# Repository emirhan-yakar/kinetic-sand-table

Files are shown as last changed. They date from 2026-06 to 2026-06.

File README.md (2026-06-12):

<div align="center">

DEVRAN

### Kinetik Kum Sanatı Masası · Polar (θ-ρ) · Ø60 cm

Çelik bir bilyeyi kumun altından mıknatısla sürükleyerek sonsuz desen çizen,
**Türkiye'de üretilebilir**, açık tasarımlı premium kinetik sanat masası.






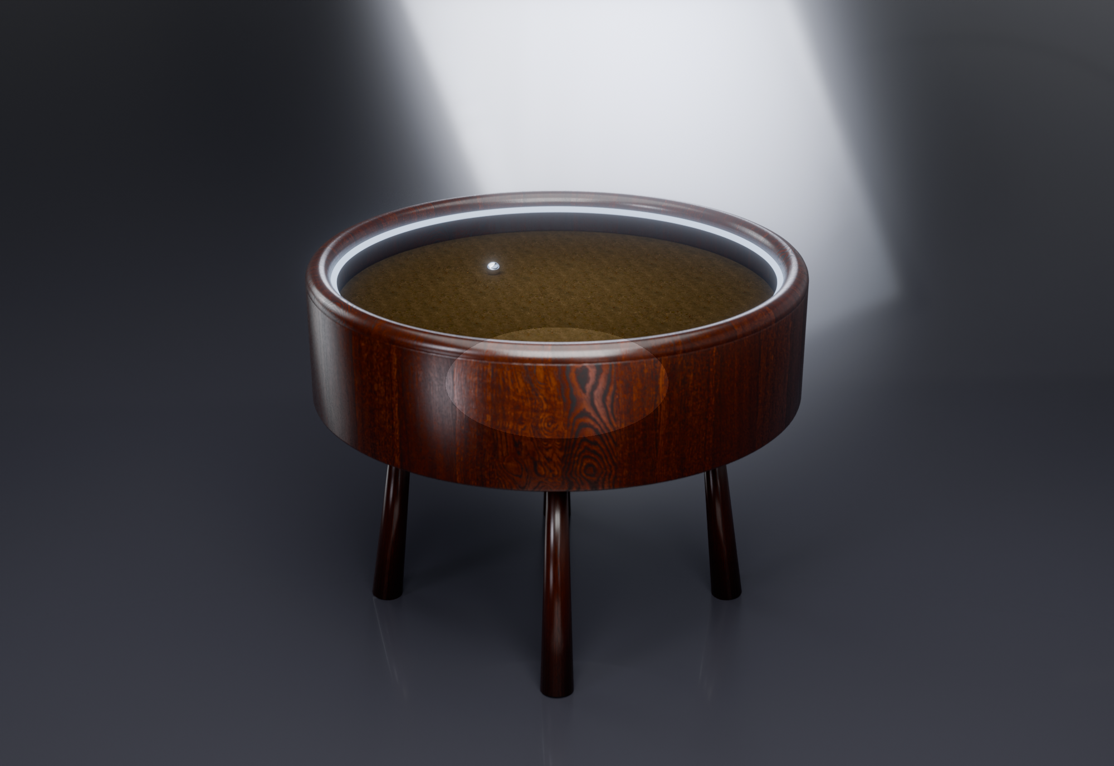
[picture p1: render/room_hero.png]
DEVRAN render


</div>

---

## Bu nedir?

DEVRAN, cam yüzeyin altında dönen bir kol (**θ** ekseni) ve kol üzerinde kayan bir taşıyıcının
(**ρ** ekseni) bir **N52 mıknatısı** taşıdığı, bu mıknatısın üstteki kumda bir **çelik bilyeyi**
sürükleyerek desen kazıdığı bir Sisyphus tipi kinetik masadır. Kenardaki **WS2812B LED halka**
ambiyans ışığı verir. Beyin bir **ESP32 + FluidNC**'dir; `.thr` (theta-rho) desenlerini oynatır.

Bu repo **fikirden satılabilir ürüne** giden tüm mühendislik + üretim dosyalarını içerir.

## Öne çıkanlar

- 🌀 Sonsuz, tekrarsız kinetik kum deseni (Atatürk imzası, spiral, özel)
- 🔇 Sessiz çalışma (TMC2209) · 💡 adreslenebilir LED ambiyans
- 📶 Wi-Fi / WebUI kontrol · SD desen kütüphanesi
- 🪵 Premium ceviz gövde + temperli cam · 🇹🇷 yerli üretilebilir
- 🔓 Açık kaynak yazılım (FluidNC + Dune Weaver)

## Üretim paketi

| Alan | Dosyalar |
|---|---|
| **Kontrol kartı** | KiCad Rev-B · Gerber · STEP · [JLCPCB paketi](hardware/pcb/jlcpcb/) (BOM+CPL) · [inceleme](docs/uretim/PCB_inceleme.md) |
| **Mekanizma** | [θ/ρ kinematik + kesit + hesap](docs/uretim/mekanizma_tasarim.md) |
| **Mekanik üretim** | [DXF + STEP](docs/uretim/dxf/) (şasi/ayak/kol) · [teknik çizim](docs/uretim/MONTAJ_CIZIM.pdf) · [montaj](docs/uretim/montaj.md) |
| **Elektrik** | [harness + pinout](docs/uretim/elektrik_montaj.md) · [talimat PDF](docs/uretim/ELEKTRIK_TALIMATI.pdf) · [QA/FCT](docs/uretim/QA_kontrol_listesi.md) |
| **Firmware** | [FluidNC config](firmware/fluidnc_config.yaml) · [mimari](firmware/README.md) |
| **İş** | [üretim dosyası (NPI)](docs/uretim/URETIM_DOSYASI.md) · [datasheet](docs/DEVRAN_datasheet.pdf) · [pitch](docs/DEVRAN_pitch.pdf) · [BOM/maliyet](docs/uretim/BOM_uretim.md) |
| **Görsel** | render + reklam videosu (`render/`) · interaktif 3D sim (`render/viewer.html`) |

> 🌐 **Web sitesi:** kök `index.html` (yerel: `python3 -m http.server`) — GitHub Pages açılırsa canlı.

## Durum (dürüst)

| Alt sistem | Durum |
|---|---|
| Mekanik tasarım | 🟡 Tasarlandı (kinematik + çizim + DXF/STEP) — fiziksel prototip yok |
| Kontrol kartı (PCB) | 🟠 Rev-B, DRC temiz — **fiziksel üretilmedi/test edilmedi** |
| Firmware | 🟠 Mimari + config hazır — cihazda doğrulanmadı |
| BOM / maliyet / görsel | 🟢 Hazır |

**Sıradaki:** Fusion'da COTS fit doğrulama → PCB sipariş → bring-up → kalibrasyon → EVT/DVT.

## Maliyet & fiyat

Seri COGS ≈ **7.800 TL** (~$230) → hedef **MSRP ≈ 21.900 TL** (~$650, ~%64 brüt marj).
Benzer ürün $699. Yazılım açık kaynak (0 TL). Detay: [BOM/maliyet](docs/uretim/BOM_uretim.md).

## Repo yapısı

```
hardware/pcb/   KiCad tasarım, Gerber, STEP, JLCPCB paketi (üretim scriptleri)
firmware/       FluidNC config + desen üreteçleri (.thr)
render/         Blender sahne (scene.py), render'lar, reklam videosu, 3D sim (viewer.html)
docs/uretim/    mekanizma, montaj, elektrik, QA, BOM, DXF+STEP, teknik çizim/PDF'ler
docs/           datasheet, pitch, gerçeklik yol haritası
*.html          web sitesi (build_site.py ile MD'den üretilen sayfalar dahil)
```

## Yeniden üretmek

```bash
# Site (MD -> HTML sayfalar)        : python3 build_site.py
# Render/video (Blender 4.5)        : Blender --background --python render/scene.py -- hero|video
# PCB (KiCad 9 + Freerouting)       : hardware/pcb/freeroute.sh
# DXF/STEP                          : python3 docs/uretim/dxf/make_dxf.py && make_step.py
# Datasheet/pitch                   : python3 docs/marka_pdf.py
```

## Lisans & katkı

Açık kaynak tasarım. Ticari üretim için: PCB **fiziksel doğrulama** + **CE/elektrik güvenlik**
belgesi gereklidir. Katkı/issue/PR memnuniyetle. Tüm değişiklikler: [CHANGELOG.md](CHANGELOG.md).

<div align="center"><sub>DEVRAN · kinetik kum sanatı masası · github.com/emirhan-yakar/kinetic-sand-table</sub></div>

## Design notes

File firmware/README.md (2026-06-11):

# Firmware & Yazılım — gerçek mimari

> **Durum:** Mimari + config **hazır**; cihaza yüklenip **doğrulanmadı** (PCB henüz üretilmedi).
> Hazır açık kaynak yazılım kullanılır — sıfırdan firmware yazmaya gerek yok.

## Mimari
Kinetik kum masaları iki katmanlı çalışır:

1. **Hareket: ESP32 + FluidNC** — G-code yorumlar, TMC2209 sürücülerle θ/ρ motorlarını sürer.
   - Pinler kontrol kartıyla eşleşir: **`fluidnc_config.yaml`** (bu klasörde).
   - FluidNC'nin kendi **WebUI**'si var; SD karttan G-code oynatabilir.
2. **Desen/UX: Dune Weaver (opsiyonel, Raspberry Pi)** — `.thr` desen kütüphanesi, canlı
   önizleme, **LED senkron (WLED)**, zamanlama. `.thr`'yi G-code'a çevirip FluidNC'ye gönderir.

```
.thr (Sandify/Dune Weaver) --(theta-rho -> G-code)--> FluidNC (ESP32) --> TMC2209 --> motorlar
                                                          └ WebUI / SD
LED: WS2812B  <-- WLED veya Dune Weaver LED modulu (idle/playing/scheduled)
```

**İki seçenek:**
- **A (sade, EVT):** Sadece FluidNC. Desenler offline `.thr→G-code` çevrilip SD'ye/WebUI'a.
- **B (tam UX, ürün):** A + Raspberry Pi Zero 2 W'de Dune Weaver app (+~500 ₺).

## Kurulum
1. **FluidNC yükle** (ESP32): https://github.com/bdring/FluidNC — web installer (`http://install.fluidnc.com`) veya esptool.
2. `fluidnc_config.yaml`'i karta yükle (FluidNC WebUI → Files veya SD). Pinler PCB ile eşleşir.
3. **Kalibrasyon (donanımda, ZORUNLU):**
   - `steps_per_mm` (X=ρ ve A=θ) gerçek dişli/mikroadıma göre ayarla (config'deki değerler tahmini).
   - ρ home (endstop) yönü/menzili; θ tam tur = doğru derece.
   - TMC2209 akımı ~0.6–0.9A (standalone'da pot/UART'da config).
4. **Desen akışı:** `firmware/patterns/*.thr` (Atatürk imza, spiral, klasik) → Sandify/Dune Weaver
   ile G-code'a çevir → oynat. (Üretici: `firmware/patterns/*.py`.)
5. **Dune Weaver (opsiyonel):** Raspberry Pi'ye kur (https://github.com/tuanchris/dune-weaver),
   FluidNC'yi seri/USB ile bağla, `.thr` kütüphanesi + LED + zamanlama.

## LED (WS2812B)
- **WLED** (ESP ayrı veya aynı) ya da Dune Weaver LED modülü ile sürülür — idle/playing/scheduled modları.
- Donanım notu: 3.3V→5V **level shifter** gerekir (bkz. `docs/uretim/PCB_inceleme.md` #2).

## Önemli — dürüst notlar
- Bu config **donanımda doğrulanmadı**; ilk bring-up'ta pin/yön/akım testleri gerekir
  (`docs/uretim/URETIM_DOSYASI.md` §5).
- İlk prototipte **standalone TMC** (UART yok) önerilir — daha az risk; UART'ı DVT'de ekle.
- Polar kinematik: θ = sürekli dönme (A ekseni), ρ = lineer (X ekseni). `.thr` (theta rad, rho 0..1)
  → G-code (A derece, X = rho×max_yarıçap). Çevrim Sandify/Dune Weaver tarafında.

## Dosyalar
- `fluidnc_config.yaml` — FluidNC pin/eksen config (PCB ile eşleşir)
- `patterns/` — `.thr` desenleri + üreteçler (imza izi, spiral, görüntü→theta-rho)

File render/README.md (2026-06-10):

# Blender Fotogerçekçi Render

Kinetik kum sanatı masasının (Ø60cm) prosedürel Blender sahnesi ve Cycles render'ı.
Geometri `hardware/sand_table.scad` ölçüleriyle kod içinde kurulur — harici STL/model gerekmez.

## Çalıştırma
```
BL=~/Applications/Blender.app/Contents/MacOS/Blender
"$BL" --background --python render_table.py -- hero    # aydınlık ürün çekimi
"$BL" --background --python render_table.py -- dark    # koyu LED parıltılı çekim
```
Çıktı: `table_hero.png`, `table_dark.png` (1600×1200, Cycles, Metal GPU + OpenImageDenoise).

## Çıktılar
| Dosya | Açıklama |
|---|---|
| `table_hero.png` | Aydınlık stüdyo: mat ceviz gövde + taranmış konsantrik kum deseni + çelik bilye + LED halka |
| `table_dark.png` | Koyu stüdyo: cam görünür, mavi LED halka kumu/camı aydınlatır (ambiyans) |

## Sahne özeti (`render_table.py`)
- **Geometri:** ahşap gövde (üst kısma boolean ile kum havuzu oyulur), kum diski,
  cam üst (hero'da kameradan gizli → desen net), çelik bilye, LED torus halka, ahşap çerçeve.
- **Malzemeler (Principled BSDF):** ceviz (prosedürel Wave damar, mat), cam (transmission 1,
  roughness 0.02, IOR 1.5), kum (Wave RINGS `Z` → konsantrik oluk bump + ince gren noise),
  çelik (metallic), LED (Emission).
- **Işık:** 4 area light (key/fill/rim/top) düşük `specular_factor` (cam/bilye ışık aynalamasın),
  yumuşak stüdyo dünyası. Dark modda key+rim azaltılıp LED gücü artırılır.
- **Kamera:** 50mm, 3/4 yüksek açı, DOF f/5.6.
- **Ton eşleme:** Filmic Medium Contrast.

## Ayar ipuçları
- Kum deseni belirginliği: `wring` Scale/Distortion + `bumpS` Strength.
- Pozlama: area light `energy` ve world `Strength`; oluk gölgesi için Top ışığı kıs, Key (yan) koru.
- Kalite: `scene.cycles.samples` (220 → 300+).
- Ayrıntılı malzeme/ışık reçetesi: `../docs/render-recipe.md`.

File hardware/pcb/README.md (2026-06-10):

# Kontrol Kartı / PCB Spesifikasyonu

## Strateji
- **Prototip (1–10 adet):** Özel PCB tasarlama. Hazır **MKS DLC32** veya
  **BTT** ESP32 tabanlı kontrol kartı kullan — TMC2209 sürücü yuvaları,
  endstop ve LED çıkışı hazır. Riski sıfırlar, hızlı doğrulama sağlar.
- **Seri (50+ adet):** Maliyet ve montaj için aşağıdaki tek kartı KiCad'de
  tasarla, **JLCPCB / PCBWay** (Çin, ucuz, SMT montaj dahil) veya yurt içi PCB
  firmasında bastır.

## Özel PCB — blok şema
```
            +12V DC giriş (fiş + ters polarite koruma D1)
               │
        ┌──────┴───────┐
   12V →│ Buck 12V→5V   │→ +5V (ESP32, LED, lojik)
        └──────────────┘
               │5V                          │12V
        ┌──────┴───────┐            ┌────────┴─────────┐
        │   ESP32-WROOM │            │ TMC2209 #1 (θ)   │→ NEMA17 θ
        │   -32         │── UART ───▶│ TMC2209 #2 (ρ)   │→ slip ring → NEMA17 ρ
        │               │   STEP/DIR └──────────────────┘
        │   GPIO ───────┼─[330Ω]─▶ DIN  WS2812B LED halka
        │   3v3 lojik   │          (5V güç + 1000µF kondansatör)
        │   GPIO ◀──────┼── endstop (θ home opto/mikro switch)
        └───────────────┘
```

## Pin haritası (Dune Weaver firmware ile uyumlu — `firmware/` bkz.)
| İşlev | ESP32 GPIO | Not |
|---|---|---|
| θ STEP / DIR | 19 / 18 | TMC2209 #1 |
| ρ STEP / DIR | 21 / 5 | TMC2209 #2 (sinyaller slip ring'den) |
| TMC UART (her ikisi) | 17 (TX)/16 (RX) | tek hat, adresli |
| EN (ortak) | 25 | sürücü enable |
| θ endstop / home | 22 | opto veya mikro switch |
| WS2812B DIN | 4 | seri direnç 330Ω |
| Buck enable / fan | 23 | opsiyonel |

## KiCad bileşen listesi (özel PCB)
- ESP32-WROOM-32E modülü (veya ESP32-DevKit header)
- 2× TMC2209 step sürücü (modül soketi veya SMD)
- MP1584 / LM2596 buck (12V→5V, ≥3A) — LED akımı için 5V hattını boyutlandır
- Giriş: DC jack/klemens, P-MOSFET ters polarite koruma, TVS diyot
- WS2812 hattı: 330Ω seri direnç + 1000µF/16V elektrolitik kondansatör
- Endstop konnektörü, motor için 4'lü JST/klemens (×2), slip ring klemensi
- Decoupling: 100nF × bolca, ESP32 EN/BOOT için RC + butonlar (programlama)

## Slip ring notu (KRİTİK — yuvarlak masaya özel)
Kol sürekli döndüğü için **ρ motorunun 4 bobin kablosu** dönen koldan sabit
karta **slip ring** üzerinden gelir. En az **6 kanallı** kapsül slip ring seç
(4 motor + 2 yedek/LED). Sinyal yerine motor bobinlerini geçirmek en basitidir
(ρ sürücüsü sabit kartta kalır). Slip ring kontak direnci düşük olmalı; ρ
akımını TMC2209'da makul (~0.6–0.9A) tut.

---

# ÜRETİLEN DOSYALAR

Kart, KiCad olmadan saf Python (`gerbonara`) ile **kod olarak** tasarlandı.
Yeniden üretmek için:
```
pip install --user gerbonara
python3 pcb_gen.py
```

## Dosya manifestosu
| Yol | İçerik |
|---|---|
| `pcb_gen.py` | Kartı üreten script (yerleşim + yönlendirme + GND plane + render) |
| `board3d.scad` | Kartın **3D dizgi modeli** (OpenSCAD → STL) |
| `controller.net` | KiCad'e aktarılabilir **netlist** (26 net) |
| `gerbers/*.gtl .gbl .gts .gbs .gto .gbo .gko` | Gerber katmanları (RS-274X) |
| `gerbers/controller-PTH.drl` / `-NPTH.drl` | Excellon delik dosyaları |
| `plots/*.svg` (+ `.png`) | Her katmanın çizimi + üst/alt kompozit + **assembly drawing** |

## Katman dizilimi (stackup) — 2 katman, 1.6mm FR4
| Gerber | KiCad adı | İçerik |
|---|---|---|
| `.gtl` | F.Cu | üst bakır: sinyal + güç izleri, padler |
| `.gbl` | B.Cu | **GND ground plane** (clearance'lı dolgu) |
| `.gts`/`.gbs` | F/B.Mask | lehim maskesi açıklıkları |
| `.gto`/`.gbo` | F/B.Silkscreen | bileşen konturları, pin-1, ratsnest kılavuzu |
| `.gko` | Edge.Cuts | kart sınırı 100×75mm + 4× Ø3.2 montaj deliği |

## Katman çizimleri (plots/)
- `composite-top.svg` / `composite-bottom.svg` — üst/alt birleşik görünüm
- `top_cu.svg`, `bot_cu.svg` (GND plane), `*_mask`, `*_silk`, `edge`
- `assembly.svg` — etiketli yerleşim/dizgi çizimi (montaj için)

## Yönlendirme durumu
- GND tamamen **alt katman ground plane** ile çözüldü (router'a girmez).
- Sinyal + güç: **26/32 segment** otomatik yönlendirildi (çakışma kontrollü).
- Kalan **6 segment** üst silk'te **kesik çizgi (ratsnest)** olarak işaretli —
  yoğun ESP32 çevresi sinyalleri. Bunlar KiCad'de elle/autorouter ile tamamlanır.

## ⚠️ Üretim öncesi (ZORUNLU)
Bu Gerber'lar geometrik olarak geçerlidir ve fabrikaya yüklenebilir, ancak
**seri üretimden önce KiCad'de DRC** (tasarım kuralı kontrolü) çalıştırılmalı:
1. KiCad → yeni PCB → `controller.net` ile **"Update PCB from netlist"**.
2. `gerbers/` Gerber'larını referans alarak yerleşimi içe aktar veya yeniden yerleştir.
3. 6 ratsnest segmentini tamamla, **DRC** çalıştır (clearance, annular ring).
4. `kicad-cli pcb export gerbers` ile doğrulanmış final Gerber + `step` 3D üret.

## Fabrikaya gönderim (JLCPCB / PCBWay)
- `gerbers/` klasörünü zip'le → yükle. 2 katman, 1.6mm, HASL, 5/5 mil rahat.
- Delikler: PTH (`-PTH.drl`) + NPTH (`-NPTH.drl`, montaj delikleri).
- Adetli dizgi (SMT) istiyorsan: özel PCB'yi SMD bileşenlerle tasarlayıp
  BOM + CPL ekle. Prototipte modüller (ESP32/TMC/buck) header'a takılır → elde lehim.

## Kart üzeri bileşenler (BOM özeti)
| Ref | Bileşen | Not |
|---|---|---|
| U1 | ESP32-DevKitC (2×15) | beyin |
| A1/A2 | TMC2209 StepStick | θ / ρ sürücü |
| BK1 | MP1584 buck | 12V→5V |
| J1 | 2p klemens | 12V giriş |
| J2/J3 | 4p klemens | θ / ρ motor (J3 slip ring'e) |
| J4 | 3p klemens | WS2812B LED (5V/DIN/GND) |
| J5 | 3p klemens | endstop (3V3/SIG/GND) |
| R1 | 330Ω 0805 | LED DIN seri direnç |
| C1 | 1000µF | 5V tampon |
| C2/C3 | 100nF 0805 | sürücü decoupling |

---

# KİCAD İLE FİNAL ÇIKTI (Gerber + STEP 3D)

Kart artık gerçek bir **KiCad 9 projesi** olarak da üretiliyor — gerçek footprint'ler,
net'ler, GND ground plane ve KiCad'in kendi motoruyla export edilmiş Gerber + STEP.

## Araç zinciri
```
python build_kicad.py   # pcbnew API ile controller.kicad_pcb uretir
bash   kicad_export.sh   # kicad-cli ile final/ -> Gerber + STEP + PDF + DRC
```
> KiCad ~/Applications/KiCad.app altında (9.0.9). `build_kicad.py` KiCad'in
> kendi python'u ile çalışır (bkz. script başı / kicad_export.sh içindeki yol tespiti).

## Üretilen dosyalar
| Yol | İçerik |
|---|---|
| `controller.kicad_pcb` | KiCad PCB (GUI'de açılır) — yerleşim + 25 net + GND zone |
| `build_kicad.py` | pcbnew ile kartı kuran script (footprint + net + iz + zone) |
| `kicad_export.sh` | kicad-cli export (Gerber/Drill/STEP/PDF/DRC) |
| `final/gerbers/*.gbr` + `controller.drl` | **KiCad'in ürettiği final Gerber + Excellon** |
| `final/controller.step` | **STEP 3D model** (2.1 MB, ISO-10303, e-CAD/mekanik için) |
| `final/top.pdf` / `bottom.pdf` | katman PDF çıktıları |
| `final/drc.json` + `DRC_SUMMARY.txt` | DRC raporu |
| `final/plots/final-B_Cu-groundplane.png` | alt katman GND plane render'ı |

## Durum — Freerouting ile TAM ROUTING ✅
- ✅ **Tüm sinyaller routlu** — DRC **ratsnest = 0** (Freerouting 23 sinyal netini
  tamamladı: 139 iz segmenti + 3 via).
- ✅ **Bakır kısa devre yok** (DRC `shorting_items = 0`).
- ✅ **Bakır clearance ihlali yok** (zone clearance kuralı self-fill geometrisine
  göre ayarlandı).
- ✅ **GND ground plane** alt katmanda dolu (clearance'lı), Gerber'da mevcut.
- ✅ **STEP 3D** geçerli (jenerik MaiXu klemens STEP modeli kütüphanede yok, atlandı).
- ⚠️ Kalan **148 DRC ihlali kozmetik**: 129'u `silk_*` (KiCad kütüphane
  footprint'lerinin kendi silkscreen'i pad/birbirine biniyor — fabrikalar kabul eder),
  geri kalan ~12'si self-fill plane artefaktı (`isolated_copper`, `starved_thermal`).
  **KiCad GUI'de `B` (Fill All Zones)** ile yeniden doldurunca bunlar da temizlenir.

## Freerouting akışı (otomatik routing)
`pcbnew` DSN export'u headless'ta çalışmadığı için DSN'i geometriden ürettik,
SES'i kendimiz ayrıştırdık. Java 25 + Freerouting 2.2.4 gerekir.
```
JAVA=~/jdk25/.../java FREEROUTING_JAR=/path/freerouting.jar bash freeroute.sh
```
| Script | İş |
|---|---|
| `make_dsn.py` | `controller.kicad_pcb` → Specctra **`controller.dsn`** (GND = B.Cu plane) |
| (Freerouting) | `controller.dsn` → **`controller.ses`** (headless autoroute) |
| `build_kicad.py` (`SES_FILE=...`) | SES route'larını fresh board'a uygula + GND plane yeniden doldur |
| `freeroute.sh` | yukarıdakileri zincirler + `kicad_export.sh` |

## Üretim öncesi son adım (KiCad GUI'de)
1. `controller.kicad_pcb`'yi aç → **`B`** ile zone'ları yeniden doldur (kozmetik DRC temizliği).
2. İstersen silkscreen referans metinlerini görünür yap / yeniden konumla.
3. **DRC** → `kicad_export.sh` ile final Gerber/STEP'i tazele.

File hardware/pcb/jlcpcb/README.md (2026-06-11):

# JLCPCB Üretim Paketi — Rev-B

Kontrol kartını **JLCPCB**'de (veya PCBWay) üretip dizdirmek için hazır dosyalar.

> ⚠️ **Bu Rev-B tasarımıdır — fiziksel olarak henüz test EDİLMEDİ.** Üretim öncesi
> bir donanımcının son incelemesi önerilir (`../../../docs/uretim/PCB_inceleme.md`).
> İlk siparişte **5 adet** (yedekli) öneririz.

## Dosyalar
| Dosya | Ne |
|---|---|
| `gerbers_revB.zip` | Fab dosyaları (Gerber + Excellon) — JLCPCB "Add gerber file" |
| `BOM_jlcpcb.csv` | SMD dizgi malzeme listesi (Comment, Designator, Footprint, LCSC) |
| `CPL_jlcpcb.csv` | Pick & place konumları (Designator, Mid X/Y, Layer, Rotation) |
| `pos_raw.csv` | KiCad ham pozisyon (ara dosya) |

## JLCPCB akışı
1. **PCB:** gerbers_revB.zip yükle → 2 katman, 1.6mm, HASL (veya ENIG). Önizlemede kontrol et.
2. **Assembly (SMT):** "PCB Assembly" aç → **BOM_jlcpcb.csv** + **CPL_jlcpcb.csv** yükle.
3. **Parça eşleştir:** her satır LCSC ile eşleşmeli. `DOGRULA` yazan 3 parça (aşağıda) JLCPCB
   kütüphanesinden seçilmeli. Diğerleri (R/C/Q1) yaygın Basic parçalar.
4. **Rotation/önizleme:** JLCPCB dizgi önizlemesinde **her parçanın dönüşünü kontrol et**
   (KiCad↔JLCPCB rotasyon farkı olabilir — özellikle SOT-23/SOT-23-5 ve polariteli D1).
5. Sipariş → ~$30–60 (5 adet, ekonomik SMT).

## ⚠️ LCSC doğrulanacak (3 parça)
| Ref | Parça | Not |
|---|---|---|
| **U2** | 74AHCT1G125 (SOT-23-5) | 3.3→5V level shifter. JLCPCB'de yoksa eşdeğer (74LVC1G125 + dikkat) veya Extended. |
| **D1** | 10V zener (SOD-323) | BZT52C10 / MMSZ5240 — polariteyi önizlemede doğrula. |
| **F1** | PTC sigorta 1206 | Akıma göre seç (~3A hold). |

> Tüm LCSC kodları sipariş anında **stok/geçerlilik** açısından doğrulanmalı (kodlar değişir).

## Elle lehimlenecek (JLCPCB SMT'ye DAHİL DEĞİL)
Bunlar modül/soket/klemens — kart geldikten sonra elle takılır/lehimlenir:
- **U1L/U1R** — ESP32-DevKitC için 1×15 soketler (modül takılır)
- **A1/A2** — TMC2209 modülleri için 2×08 soketler
- **BK1** — buck modülü için 1×04 soket
- **J1–J5** — vidalı klemensler (12V, θ/ρ motor, LED, endstop)
- **C1 (1000µF), C6 (100µF)** — elektrolitik kondansatörler (THT)

## Üretim sonrası
Kart geldiğinde **bring-up testi** yap: `../../../docs/uretim/URETIM_DOSYASI.md` §5.1
(motor bağlamadan güç → 5V ölç → FluidNC flash → UART adres oku → LED test).

## Yeniden üretmek
```
kicad-cli pcb export pos --format csv --units mm --side both --use-drill-file-origin -o jlcpcb/pos_raw.csv controller.kicad_pcb
python3 make_jlcpcb.py
```

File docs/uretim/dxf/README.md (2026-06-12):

# CNC / Lazer Kesim DXF Dosyaları

Alüminyum şasi, ayak plakası ve dönen kol için 2D kesim dosyaları (mm, DXF R2010).
Lazer / CNC router / su jeti atölyesine doğrudan gönderilebilir.

| Dosya | Parça | Malzeme / kalınlık | Adet |
|---|---|---|---|
| `sasi.dxf` | Mekanizma şasi diski Ø520 | Alüminyum **6082 / 5754, 4 mm** | 1 |
| `ayak_plakasi.dxf` | Ayak bağlantı plakası 60×60 | Alüminyum 4 mm veya çelik 3 mm | **4** |
| `kol.dxf` | Dönen kol (θ) 320×40 | Alüminyum 5 mm | 1 |

Her `.dxf` yanında `*_preview.png` (görsel kontrol).

## 3D STEP (mekanik CAD doğrulama)
Aynı parçalar **3D katı** olarak da var (`*.step`) — Fusion 360 / FreeCAD / SolidWorks'te
açıp montaj/fitment doğrulamasına başlamak için (`make_step.py`, cadquery ile üretildi):
`sasi.step` (Ø520×4, 820 cm³) · `ayak_plakasi.step` (60×60×4) · `kol.step` (320×40×5).
> Bunlar **kesim parçalarının** katılarıdır; tam fitment için satın alınan COTS parçaları
> (MGN12 ray, lazy-susan, slip ring, NEMA17) CAD'e ekleyip doğrula.

## Delik şeması (özet)
- **Şasi:** dış Ø520 · drum bağlantı 4× M4 @ Ø500 PCD · merkez Ø90 (slip ring + kayış boşluğu) ·
  turntable 4× M4 @ Ø120 · θ motor NEMA17 (Ø22 + 4× M3 @ 31×31, offset) · PCB 4× M3 (92×67) · kablo yuvası.
- **Ayak plakası:** 60×60 · 4× M5 @ 36×36 · merkez Ø20 (ayak tenon). **8° splay açısı plakada değil,
  eğimli ayak/braket veya ara takozda** verilir (DXF düz kesimdir).
- **Kol:** pivot ucu 4× M3 @ Ø30 + merkez Ø8 · MGN12 ray M3 @ 20 mm · ρ motor NEMA17 ucu.

## ⚠️ Üretim öncesi doğrulama (ZORUNLU)
Delik konumları **temsilidir** — atölyeye göndermeden önce **gerçek parçalarla** doğrula:
- **MGN12 ray** delik pitch'i (20 vs 25 mm) → satın alınan raya göre.
- **Lazy-susan / turntable** civata dairesi → satın alınan rulmana göre.
- **Slip ring** gövde/bore çapı → seçilen modele göre (merkez Ø90 boşluk).
- **NEMA17** = standart (31×31 M3, Ø22 pilot) ✓.
- Toleranslar: gecme delikler (M3=3.2, M4=4.5, M5=5.5); sıkı geçme gerekiyorsa düşür.

> Bunlar 2D **kesim** dosyalarıdır; 3D montaj/açı için `montaj.md`, `montaj_sheet.svg`,
> `montaj_patlatma.png`. Nihai mekanik CAD (Fusion 360 / SolidWorks) ile son kontrol önerilir.

## Yeniden üretmek
```
python3 make_dxf.py    # ezdxf gerekir:  pip install ezdxf
```
Ölçüler `make_dxf.py` başındaki sabitlerden (montaj_hesap.py ile tutarlı) gelir.

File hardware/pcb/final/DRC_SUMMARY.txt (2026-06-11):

KiCad 9.0.9 DRC -- Rev-B (Freerouting tam routing)
ratsnest: 0 | bakir short: 0 | bakir clearance: 1
toplam ihlal: 171 (cogu kozmetik silk + plane artefakti; GUI 'B' refill ile temizlenir)
    73 silk_over_copper
    73 silk_overlap
    10 isolated_copper
     6 starved_thermal
     3 courtyards_overlap
     2 solder_mask_bridge
     2 silk_edge_clearance
     1 clearance
     1 hole_clearance

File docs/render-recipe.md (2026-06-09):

# Fotogerçekçi Render Reçetesi (Blender Cycles / KeyShot)

`hardware/sand_table.scad` modelinden STL al → Blender'a import et (veya Fusion
360'ta yeniden modelleyip KeyShot'a gönder). Aşağıdaki reçete tanıtım/ürün
görseli kalitesinde sonuç verir.

## 1) Model hazırlığı
- OpenSCAD'de `EXPLODE=0`, `SHOW_GLASS=true`, `SHOW_SAND=true` → Export STL.
- Blender: Import STL → ölçek mm→m (0.001) kontrol et → `Shade Smooth` gövde.
- Kum yüzeyine **gerçek desen** için: Sandify'dan bir `.thr`/SVG yörüngesini
  curve olarak import et, ince oluk (displacement) olarak kuma uygula.

## 2) Malzemeler (Principled BSDF)
| Parça | Ayar |
|---|---|
| Ahşap gövde | Base color koyu ceviz doku (Roughness 0.4, hafif clearcoat) |
| Cam üst | Transmission 1.0, Roughness 0.02, IOR 1.5, ince kalınlık |
| Kum | Base color #DBC79E, Roughness 0.9 + **Displacement** (noise + desen yörüngesi) |
| Çelik bilye | Metallic 1.0, Roughness 0.08 |
| Metal mekanizma | Metallic 1.0, Roughness 0.3 |
| LED halka | Emission, renk seçilebilir (örn. mavi/turkuaz), Strength 4–8 |

## 3) Aydınlatma
- **HDRI** stüdyo ortamı (Poly Haven `studio_small_*`) — yumuşak yansıma.
- 1 ana softbox (area light, üstten 45°), 1 dolgu, 1 arka kenar ışığı.
- LED halkanın emission'ı sahneye renk sızdırsın (karanlık çekim için ortam ışığını kıs).

## 4) Kamera & kompozisyon
- 35–50mm lens, hafif üstten 3/4 açı (deseni gösterir).
- İkinci kare: tam tepeden (top-down) sadece kum deseni + LED parıltısı.
- DOF: f/4 civarı, bilyeye odak.

## 5) Render ayarları (Cycles)
- 1024–2048 sample + OpenImageDenoise.
- Film transparent (PNG, sonradan zemin) veya stüdyo zemini (soft gradient).
- Çözünürlük 2000×2000+ (ürün sayfası/e-ticaret için kare).

## 6) İki ortam çekimi
1. **Aydınlık ürün shot'u** — ahşap+cam dokusu, premium his.
2. **Karanlık ortam shot'u** — LED halka parlıyor, kum deseni ışıkla vurgulu.

## Alternatif hızlı yol
Fusion 360'ta modelle → yerleşik **Render** çalışma alanı veya KeyShot'a köprü →
hazır malzeme kütüphanesiyle dakikalar içinde fotogerçekçi çıktı.

> Not: Bu reçeteden çıkan görseller e-ticaret ürün sayfası ve reklam için yeterli
> kalitededir. İstersen Blender için hazır `.blend` sahne kurulum scriptini de
> (Python) yazabilirim.

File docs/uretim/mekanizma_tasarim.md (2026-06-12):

# Mekanizma Tasarımı — polar (θ-ρ) kinetik sürücü

Bilyeyi kumun altından mıknatısla sürükleyen **dönen-kol (rotating arm)** mekanizması.
Sisyphus/Dune Weaver tipi. Mevcut **kontrol kartı** (J3 = ρ motor, J5 = endstop) ve **FluidNC**
(X = ρ, A = θ) ile **tutarlı** tasarlanmıştır.

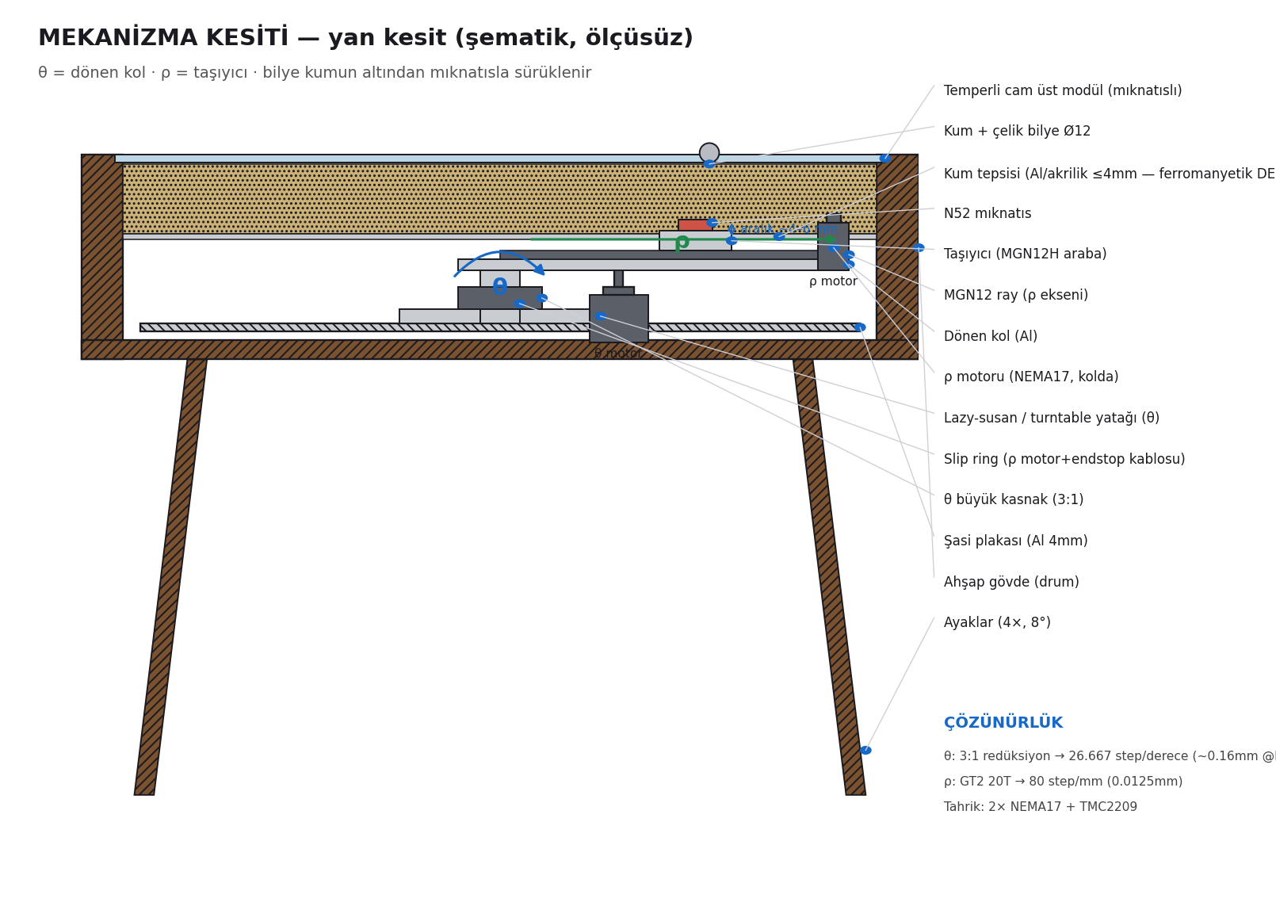
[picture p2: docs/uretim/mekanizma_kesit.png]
mekanizma kesiti


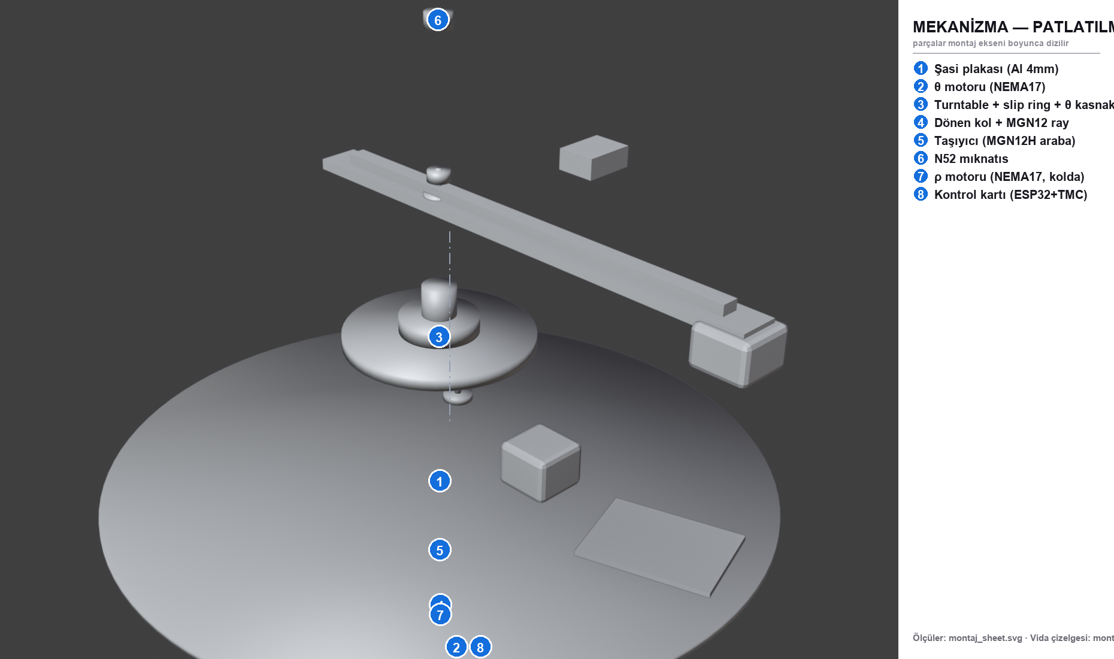
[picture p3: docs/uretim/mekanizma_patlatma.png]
mekanizma patlatılmış


## 1) Mimari ve katman dizilimi (alttan üste)
```
   ┌─ cam (temperli Ø552)                              ← sabit (üst modül, mıknatıslı)
   │   kum + çelik bilye (Ø12 krom)                    ← sabit tepsi içinde
   ├─ KUM TEPSİSİ tabanı (alüminyum/akrilik ≤4mm, ferromanyetik DEĞİL)  ← sabit
   │      ↕ hava aralığı ~4–6 mm   (manyetik kuplaj)
   │   ┌ MIKNATIS (N52) — taşıyıcı üstünde
   │   ├ TAŞIYICI (MGN12H araba) ── MGN12 RAY ─────────  ← DÖNEN kol üstünde (ρ ekseni)
   ├─ DÖNEN KOL (Al 5mm)  + ρ motoru (NEMA17, kolda) + GT2 kayış
   ├─ LAZY-SUSAN / turntable rulman (Ø100–150)          ← θ dönme yatağı
   ├─ ŞASİ plakası (Al 4mm, sabit)                       ← sasi.dxf/step
   │   θ motoru (NEMA17, şasi altında) + GT2 redüksiyon
   │   SLIP RING (kapsül, merkez) — ρ motor+endstop kablosu döner tarafa
   └─ kontrol kartı + 12V SMPS (şasi altı/yanı)
```

## 2) θ ekseni (dönme)
- **Yatak:** Lazy-susan / turntable rulman (Ø100–150 mm) veya ince-kesit bilyalı rulman.
  Kolu + ρ tertibatını taşır, merkezde slip ring için **boşluk** (Ø≥40).
- **Tahrik:** NEMA17 → **GT2 kayış**, motor kasnağı **20T** → eksen kasnağı **60T** = **3:1 redüksiyon**.
  (tork + çözünürlük artışı; ucuz, geri boşluksuza yakın).
- **Çözünürlük:** 1.8° motor × 16 µstep = 3200 step/dev × 3 = **9600 step / kol turu** → **26.667 step/derece**.
  R=250 mm'de yay çözünürlüğü = 2π·250·(0.0375°/360) ≈ **0.16 mm** (sub-mm ✓).
- **Sürekli dönme:** FluidNC **A** ekseni limitsiz; slip ring kabloyu sınırsız tur sağlar.

## 3) ρ ekseni (yarıçap)
- **Ray:** **MGN12** lineer ray (kol boyunca), **MGN12H** araba = taşıyıcı.
- **Tahrik:** kolun pivot ucunda **NEMA17** (kolla birlikte döner) → **GT2 kapalı kayış** → taşıyıcı.
  Kasnak **20T** = 40 mm/dev.
- **Çözünürlük:** 3200 step/dev / 40 mm = **80 step/mm** → 0.0125 mm/step (✓).
- **Strok:** 0 → R_max ≈ **250 mm** (ray ~280 mm). Merkez ucunda **endstop** (ρ home).
- FluidNC **X**: `steps_per_mm: 80`, `max_travel_mm: ~250`.

## 4) Slip ring (dönen tarafa güç+sinyal)
ρ motoru kolla döndüğü için kablosu **kapsül slip ring**'ten geçer (merkez ekseninde):
- **Geçen iletkenler:** ρ motor 4 (A+,A−,B+,B−) + endstop 2 = **6 hat** → **8–12 yollu, ≥2A** kapsül slip ring (Ø12.5).
- Sürücüler **bazda** (ana PCB): J3 → slip ring → ρ motor; J5 → slip ring → endstop. **PCB ile tutarlı.**
- LED **sabit** rim'de → slip ring **gerekmez**.

## 5) Mıknatıs ve kuplaj
- **Mıknatıs:** N52 **Ø20×10** (veya Ø15×8), taşıyıcı üstünde, kutup yukarı.
- **Aralık:** tepsi tabanı (≤4 mm, **ferromanyetik değil**) + hava ~4–6 mm = toplam ~8–10 mm.
- **Bilye:** Ø12 krom çelik. Bu aralıkta N52 Ø20×10 çekme kuvveti ≫ ince kumda sürükleme direnci
  (tipik <1 N orta hızda) → güvenli kuplaj. Aralık büyürse mıknatısı büyüt / kademe yap.

## 6) Hesap özeti
| Büyüklük | Değer |
|---|---|
| θ step/derece | **26.667** (3200×3 / 360) |
| θ çözünürlük @R250 | **0.16 mm** |
| ρ step/mm | **80** (3200 / 40) |
| ρ çözünürlük | **0.0125 mm** |
| ρ strok | ~250 mm |
| θ redüksiyon | 3:1 (20T→60T GT2) |
| Motor | 2× NEMA17 (1.8°, ~0.4 N·m), TMC2209 ~0.6–0.9A |

## 7) Yükseklik / sığma bütçesi (drum gövdesi ~147 mm)
Şasi 4 + lazy-susan ~10 + kol 5 + ray+araba ~21 + mıknatıs/aralık ~10 ≈ **50 mm** (tepsi altına).
θ motoru şasi **altında** (34 mm). **ρ motoru (34 mm) kolda** en yüksek öğe → ya kol ucunda yana
sarkıtılır ya gövde yüksekliği buna göre. → **Doğrulanacak fit kalemi.**

## 8) Eklenecek BOM (mekanizma)
| Parça | Örnek | TR tedarik |
|---|---|---|
| Lazy-susan/turntable rulman Ø100–150 | turntable bearing | yatak/robotik satıcı |
| GT2 kayış + kasnak 20T/60T + idler | 6 mm GT2 set | Robotistan/Motorobit |
| MGN12 ray + MGN12H araba (~300 mm) | MGN12 | lineer hareket satıcı |
| Kapsül slip ring 8–12 yol ≥2A | Ø12.5 kapsül | robotik/otomasyon |
| N52 mıknatıs Ø20×10 | neodyum | yurtiçi neodyum |
| Krom çelik bilye Ø12 | bilye | rulman/bilye satıcı |

## 9) Firmware tutarlılığı (`../../firmware/fluidnc_config.yaml`)
- **A (θ):** `steps_per_mm: 26.667`, sürekli (`max_travel` büyük).
- **X (ρ):** `steps_per_mm: 80.0`, `max_travel_mm: 250`, `limit_neg_pin` (endstop, slip ring'den).
- `.thr` (θ rad, ρ 0..1) → G-code: **A = derece**, **X = ρ × 250 mm**.

## 10) Riskler ve doğrulama
| Risk | Önlem / doğrulama |
|---|---|
| θ yatak boşluğu/salınımı → desen kayması | kaliteli ince-kesit rulman; kayış gerginliği |
| ρ motoru kolda yükseklik | fit testi (gövde yüksekliği vs motor) — **Fusion'da STEP ile doğrula** |
| slip ring gürültü/kontak | ≥2A kaliteli kapsül; ρ akımını düşük tut |
| mıknatıs aralığı büyük → bilye kaçar | aralığı ≤10 mm tut; gerekirse mıknatıs büyüt; hız limiti |
| kuplaj hızda kopar | max_rate'i kalibrasyonda bul (FluidNC) |

> **Sonraki adım:** bu mimariyi **Fusion 360**'a aktar (STEP + COTS: MGN12, lazy-susan, slip ring,
> NEMA17 modelleri) → fit/çakışma + yükseklik bütçesini doğrula. Bu doküman o doğrulamanın girdisidir.

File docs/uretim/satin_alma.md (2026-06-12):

# Prototip Satın-Alma & Tedarikçi Listesi

**Bir adet çalışan prototip** için somut alışveriş listesi. Para harcama anına en yakın doküman.

- 💰 **Malzeme toplamı ≈ 11.400 TL** (+ kargo + ~%10 yedek pay → bütçe **~13–14k TL**)
- 📋 Sipariş/takip için tablo: [`satin_alma.csv`](satin_alma.csv) (üreteç: `satin_alma.py`)
- ⚠️ Fiyat/stok **2026 TR tahmini** — sipariş anında doğrula. Tedarikçi adları + arama terimi verildi
  (canlı link/fiyat değişir).

## Sipariş stratejisi (önce uzun-terminliler!)
| Öncelik | Kalem | Termin | Neden |
|---|---|---|---|
| 1 | **PCB+SMT (JLCPCB)** · **slip ring** · **CNC ahşap gövde** | 1–2 hafta+ | en uzun termin → ilk sipariş et |
| 2 | MGN12 ray · lazy-susan · GT2 set · cam · Al lazer | 3–7 gün | orta termin |
| 3 | ESP32/TMC2209/buck/motor/LED/mıknatıs/sarf | 2–5 gün | hızlı, son sipariş |

> PCB: hazır [JLCPCB paketi](../../hardware/pcb/jlcpcb/) (Gerber+BOM+CPL) yükle.
> Alüminyum/ayak plakaları: [DXF + STEP](dxf/) atölyeye gönder. Cam: [montaj_sheet](montaj_sheet.svg) ölçüsü.

## 1) Elektronik / kontrol — ~2.270 TL
| Parça | Spec | Ad | Tedarikçi | Birim | Toplam |
|---|---|--:|---|--:|--:|
| Kontrol kartı PCB+SMT | Rev-B, 5 adet | 1 | JLCPCB/PCBWay | 1.600 | 1.600 |
| ESP32-DevKitC | WROOM-32 (ön-sertifikalı) | 1 | Robotistan/Motorobit | 170 | 170 |
| TMC2209 sürücü | StepStick, UART | 2 | Robotistan/Motorobit | 125 | 250 |
| Buck 12→5V | ≥5A | 1 | Robotistan | 90 | 90 |
| Klemens/header/sarf | 2.54mm + 5mm | 1 | Direnç.net | 160 | 160 |

## 2) Motor & hareket — ~1.805 TL
| Parça | Spec | Ad | Tedarikçi | Birim | Toplam |
|---|---|--:|---|--:|--:|
| NEMA17 step motor | 1.8°, ~0.4 N·m | 2 | Robotistan | 260 | 520 |
| MGN12 ray + araba | ~300mm + MGN12H | 1 | lineer hareket satıcı | 470 | 470 |
| Lazy-susan rulman | Ø100–150 | 1 | yatak/robotik | 160 | 160 |
| GT2 kayış+kasnak seti | 6mm 2m + 20T×2 + 60T + idler | 1 | Robotistan | 260 | 260 |
| **Kapsül slip ring** | Ø12.5 · 8–12 yol · ≥2A | 1 | otomasyon/Aliexpress | 360 | 360 |
| Endstop | mekanik/opto | 1 | Robotistan | 35 | 35 |

## 3) Mıknatıs & bilye — ~403 TL
| Parça | Spec | Ad | Tedarikçi | Birim | Toplam |
|---|---|--:|---|--:|--:|
| N52 taşıyıcı mıknatıs | Ø20×10 | 3 | yurtiçi neodyum | 45 | 135 |
| N52 üst modül mıknatıs | Ø20×3 | 8 | yurtiçi neodyum | 26 | 208 |
| Krom çelik bilye | Ø12 | 5 | rulman/bilye satıcı | 12 | 60 |

## 4) Güç + LED — ~590 TL
| Parça | Spec | Ad | Tedarikçi | Birim | Toplam |
|---|---|--:|---|--:|--:|
| 12V SMPS (CE'li) | ≥6A kapalı kasa | 1 | Samm/Robotistan | 320 | 320 |
| Güç kablosu + fiş | topraklı IEC | 1 | elektrik malz. | 60 | 60 |
| WS2812B LED | 60 LED halka/şerit | 1 | Samm/LED Pazarı | 210 | 210 |

## 5) Gövde & yapı — ~5.850 TL
| Parça | Spec | Ad | Tedarikçi | Birim | Toplam |
|---|---|--:|---|--:|--:|
| Ceviz kaplama gövde (CNC) | drum Ø600 (prototip tek) | 1 | yerel CNC ahşap atölyesi | 3.200 | 3.200 |
| Masif ceviz ayak (torna) | 8°, L320 | 4 | ahşap torna/mobilya | 200 | 800 |
| Lake/finiş | mat koruyucu | 1 | boya malz. | 300 | 300 |
| Temperli cam Ø552×6 | low-iron, rodajlı | 1 | yerel temperli cam | 800 | 800 |
| Al lazer kesim (DXF) | şasi + kol + 4 ayak plakası | 1 | sac/Al lazer atölyesi | 750 | 750 |

## 6) Bağlantı / sarf — ~640 TL
| Parça | Spec | Ad | Tedarikçi | Birim | Toplam |
|---|---|--:|---|--:|--:|
| Vida/somun/standoff/insert | M3/M4/M5/M6 + gömme dişli | 1 | hırdavat/Robotistan | 260 | 260 |
| Kablo yönetimi | kanal/spiral/ferrül/etiket | 1 | elektrik malz. | 150 | 150 |
| İnce kuvars kum | ~1.5 kg | 1 | hobi/akvaryum | 80 | 80 |

## Tedarikçi rehberi (TR)
- **Elektronik/motor/ray/GT2/endstop:** Robotistan, Motorobit, Direnç.net
- **LED / güç:** Samm Teknoloji, LED Pazarı · toplu: LCSC / AliExpress
- **N52 mıknatıs:** yurtiçi neodyum satıcıları (arama: "N52 Ø20")
- **Slip ring:** otomasyon/robotik (arama: "kapsül slip ring 12mm 12 yol")
- **Ahşap gövde/ayak:** yerel CNC ahşap / mobilya atölyesi (DXF + ölçü ver)
- **Temperli cam:** yerel temperli cam imalatçısı (Ø552×6, rodaj iste)
- **Alüminyum lazer:** sac/Al lazer atölyesi ([DXF](dxf/) gönder)
- **PCB:** JLCPCB / PCBWay ([paket](../../hardware/pcb/jlcpcb/)) veya yurtiçi PCB

## Sonraki adım
Sipariş → gelince [bring-up testi](QA_kontrol_listesi.md) (önce motorsuz güç) → [montaj](montaj.md) →
[FluidNC kalibrasyon](../../firmware/README.md). Risk kontrolü: [FMEA](fmea.md).

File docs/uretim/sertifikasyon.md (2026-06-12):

# Sertifikasyon & Uyumluluk Yol Haritası

Premium, **şebeke beslemeli (adaptörlü), ağ bağlantılı, ağır cam + güçlü mıknatıs** içeren bir
mobilya-elektronik ürünü global satmak için gerekenler. Bunlar **pazarlık dışı** — yoksa yasal satılamaz.

> Strateji: ürün **SELV (≤24V DC)** tarafında kalsın; şebeke gerilimi **harici, zaten sertifikalı
> bir adaptörde** olsun → ürünün kendi sertifikasyon yükü ciddi azalır (en kritik tasarım kararı).

## 1) Hedef pazara göre zorunlu işaretler
| Pazar | İşaret / standart | Kapsam |
|---|---|---|
| **AB** | **CE** — EMC 2014/30, LVD/(adaptör), **EN 62368-1** (AV/BT emniyet), **RoHS** 2011/65, **REACH**, WEEE | emniyet + EMC + kimyasal + e-atık |
| **AB radyo** | **RED 2014/53** (Wi-Fi/BT) | telsiz modülü (ESP32) — **ön-sertifikalı modül kullan** |
| **ABD** | **FCC Part 15B** (+15C telsiz) | EMC / radyo |
| **İngiltere** | **UKCA** | CE muadili |
| **Kanada** | ISED | radyo |
| **Genel** | **EN 60335** (ev aletleri) *veya* 62368-1 + mobilya **devrilme/stabilite** | mekanik emniyet |

## 2) Ürün-özel emniyet riskleri (test edilmeli)
- **Güçlü mıknatıs (N52):** sıkışma/yutma; çocuk erişimi; manyetik alan (kalp pili uyarısı, ambalaj ikazı).
- **Temperli cam:** kırılma davranışı (temperli zorunlu), kenar emniyeti, yük dayanımı.
- **Devrilme/stabilite:** sehpa standardı (örn. ağırlık + ayak açısı; biz 8° splay + SF 5.2× ile tasarladık).
- **Isınma:** motor/sürücü yüzey sıcaklığı sınırları; uzun çalışmada.
- **Sıkışma:** mıknatıslı üst modül (≈21.6 kgf) — parmak ikazı + tasarımsal emniyet.

## 3) Akış ve tahmini bütçe (TR'den global)
| Adım | Ne | Tahmini maliyet | Süre |
|---|---|---|---|
| Ön-uyumluluk (pre-scan) | EMC ön-tarama (akredite lab) — erken hata yakala | 15–40k ₺ | 1–2 hafta |
| Tasarım düzeltme | filtre, kılıflama, topraklama | mühendislik | — |
| **CE dosyası** | EMC + 62368 emniyet testi + teknik dosya + DoF (Declaration of Conformity) | 80–200k ₺ | 4–8 hafta |
| **FCC** | Part 15B (ABD hedefliyse) | 60–150k ₺ | 3–6 hafta |
| RoHS/REACH | malzeme beyanı + (gerekirse) test | 10–30k ₺ | 1–3 hafta |
| Telsiz | **ön-sertifikalı ESP32 modülü** → modül sertifikası devral (büyük tasarruf) | düşük | — |

> Rakamlar TR akredite lab (TÜRKAK) / TÜV SÜD / Intertek / SGS / Eurofins seviyesi tahminidir;
> kapsam ve adetle değişir. **Modül sertifikası devralma** ve **harici adaptör** en büyük iki tasarruf.

## 4) Akredite test lab seçenekleri (TR / global)
TÜV SÜD · TÜV Rheinland · Intertek · SGS · Eurofins · UL · (TR akredite EMC labları).
Erken aşamada **bir labla ön-görüşme** → kapsam/maliyet netleşir.

## 5) Tasarım tarafında şimdi yapılabilecekler (pre-compliance)
- **Ön-sertifikalı ESP32 modülü** (FCC/CE/RED ID'li) seç → telsiz testini büyük oranda atla.
- **Harici CE'li adaptör** (12V DC) → şebeke emniyeti adaptörde.
- **EMC için PCB'de:** giriş filtresi, ferrit, düzgün GND, ekranlı motor kablosu (Rev-C'de eklenebilir).
- **Topraklama / SELV ayrımı**, sigorta (zaten Rev-B'de).
- Kullanım kılavuzunda **mıknatıs/cam/çocuk** ikazları + ambalaj sembolleri.

## 6) Belgeler (teknik dosya içeriği)
Teknik dosya, DoF, test raporları, risk analizi ([FMEA](fmea.md)), şema/PCB, BOM, kullanım kılavuzu,
etiket/işaretleme. Üretim sürekliliği için **üretim kontrolü** (FAI/QA — [QA fişi](QA_kontrol_listesi.md)).

> **Önce hangi pazar?** AB+TR ile başla (CE+UKCA yoksa bile AB), ABD'yi (FCC) ölçeklerken ekle.
> İlk hedef tek pazar → maliyet/odak.

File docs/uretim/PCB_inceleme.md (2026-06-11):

# PCB Elektriksel İnceleme — dürüst değerlendirme

**Kart:** ESP32 + 2× TMC2209 + WS2812 + güç (`hardware/pcb/controller.kicad_pcb`)

## Durum (net)
- ✅ **Rev-B uygulandı** — aşağıdaki inceleme bulguları `build_kicad.py`'ye işlendi,
  yeniden route edildi (Freerouting), **DRC: 0 short, 0 ratsnest, 0 bakır clearance**.
  Yeni Gerber + STEP üretildi (`hardware/pcb/final/`).
- ✅ Rev-B eklenen bileşenler: **U2** (74AHCT1G125 level-shifter), **F1** (sigorta) +
  **Q1** (P-FET ters polarite) + **D1/R2** (gate clamp/pulldown), **C6** (100µF bulk),
  **C7/C8** (VM decap), **R3** (10k EN pull-up), **R4** (1k UART), ayrı UART adresleri.
- ❌ **Hâlâ fiziksel ÜRETİLMEDİ/TEST EDİLMEDİ.** Rev-B tasarımı dondurdu; sıra prototip + bring-up.
- ⚠️ Rev-B tasarım değerleri (P-FET parça seçimi, zener 10V, PTC ~3A) **üretim öncesi
  bir donanımcı tarafından son kez gözden geçirilmeli** (özellikle Vgs limiti / koruma topolojisi).

> DRC "geometri/clearance" kontrolüdür — **devrenin doğru çalışacağını garanti etmez.**
> Aşağıdakiler ancak gözden geçirme ile yakalanır.

---

## Bulgular ve düzeltmeler (üretim öncesi ZORUNLU)

| # | Bulgu | Risk | Düzeltme (Rev-B) |
|---|---|---|---|
| 1 | **TMC2209 UART adres çakışması** — A1 ve A2'nin MS1/MS2 pinleri aynı nete (N_MS1/N_MS2) bağlı → iki sürücü **aynı UART adresi** → ayrı ayrı adreslenemez | Yüksek (UART config çalışmaz) | Her sürücüye **ayrı adres**: A1 MS1=GND,MS2=GND (adr 0); A2 MS1=VIO,MS2=GND (adr 1). MS pinlerini ayır. |
| 2 | **WS2812 data seviye uyumu** — DIN 3.3V (GPIO4 üzerinden 330Ω); 5V WS2812 HIGH eşiği ~3.5V > 3.3V | Orta (kararsız LED) | **Level shifter** (74AHCT125) 3.3→5V, veya ilk pikseli ~4.3V besle, ya da 3.3V toleranslı SK6812. |
| 3 | **Yarım-çift UART eksik bağlantı** — sürücü PDN_UART tek hat; ESP32 TX→1k→PDN ve RX←PDN gerekir; mevcut tasarımda 1k yok, RX hattı sürücülere bağlı değil | Orta (UART iletişim) | TX'e **1kΩ** seri + RX'i PDN hattına bağla (tek-hat half-duplex). |
| 4 | **VM (12V) bulk kondansatör yok** — sürücü yanında 12V tampon eksik (datasheet ≥100µF önerir) | Orta (motor gürültü/reset) | Her sürücü VM'ine yakın **100µF/25V** + 100nF. |
| 5 | **Giriş koruması yok** — 12V girişte ters polarite koruması ve sigorta yok | Orta (yanlış bağlantıda hasar) | **P-MOSFET ters polarite** + **sigorta/PTC** (örn. 5A). |
| 6 | **EN boot durumu** — sürücü EN (active-low) boot anında belirsiz → motor istem dışı sürülebilir | Düşük/Orta | **10kΩ pull-up** (EN→VIO) → boot'ta sürücüler pasif. |
| 7 | **GPIO5 strapping** — ρ DIR = GPIO5 (strapping pin) | Düşük | TMC DIR yüksek-Z giriş olduğu için kabul edilebilir; istenirse non-strapping GPIO (33) kullan. |

## Basitleştirme önerisi (EVT için risk azaltıcı)
İlk prototipte **UART'ı atla, sürücüleri standalone modda** kullan (MS1/MS2/SPREAD pinleriyle
mikro-adım + akım onboard ayar). FluidNC STEP/DIR ile çalışır; #1 ve #3 bulguları **ortadan kalkar.**
UART'ı (runtime akım/mikroadım) DVT'de ekle. → daha az arıza noktası, daha hızlı bring-up.

## Üretim öncesi adım sırası
1. Rev-B: bulguları KiCad'de uygula (build_kicad.py'de net/komponent ekle), DRC + **göz incelemesi**.
2. (Önerilir) hızlı **breadboard doğrulaması**: ESP32 + 2 TMC2209 modül + 1 LED → FluidNC bring-up,
   hat/pin doğrula → ardından PCB'ye geç.
3. PCB'yi **5 adet** bastır+dizgi (yedekli), `bring-up` testi (`URETIM_DOSYASI.md` §5.1).
4. Firmware entegrasyon testi → DVT.

## Güç bütçesi (kontrol)
- 5V: ESP32 ~0.25A + sürücü VIO ~0.05A + **WS2812 60 LED × ~60mA(max) = 3.6A** → buck **≥4–5A** şart (BOM'da var). İdle/tipik çok düşük; max tam-beyaz tasarım sınırı.
- 12V: 2× NEMA17 ~0.6–0.9A/faz → ~2–3A tepe → 12V 6A SMPS yeterli.

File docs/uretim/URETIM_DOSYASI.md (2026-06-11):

# Üretim Gerçekleme Dosyası — Kinetik Kum Masası
### (Manufacturing Readiness / Product Realization Dossier)

Bu belge ürünü **gerçek, satılabilir bir ürüne** dönüştürmek için yol haritasıdır.
Bir deneme değil; profesyonel donanım ürün geliştirme (NPI) disiplinine göre yazılmıştır.
**Dürüstlük ilkesi:** her alt sistemin gerçek olgunluk durumu açıkça belirtilir — "tasarlandı"
ile "doğrulandı" ve "fiziksel test edildi" karıştırılmaz.

---

## 0) DÜRÜST DURUM ÖZETİ (en kritik kısım)

| Alt sistem | Durum | Açıklama |
|---|---|---|
| Mekanik tasarım (Ø600 polar, ayak, mıknatıslı modül) | 🟡 **Tasarlandı** | Parametrik geometri + ölçülü montaj sheet + patlatma çizimi. **Fiziksel prototip yapılmadı.** |
| Kontrol kartı (PCB) | 🟠 **Rev-B tasarlandı (bulgular işlendi), DRC temiz — FİZİKSEL TEST EDİLMEDİ** | İnceleme bulguları (UART adres, LED level-shifter, koruma, bulk cap, EN pull-up) `build_kicad.py`'ye işlendi, yeniden route edildi (0 short). **Hâlâ lehimlenmedi/ölçülmedi.** Bkz. `PCB_inceleme.md`. |
| Firmware | 🟠 **Yazılmadı — mimari + config taslağı var** | Hazır açık kaynak **FluidNC** (hareket) + **Dune Weaver** (desen/web) kullanılacak. Örnek `firmware/fluidnc_config.yaml` hazırlandı ama **cihaza yüklenip doğrulanmadı.** |
| Görseller/render/video | 🟢 **Hazır** | Reklam kalitesinde (ön-görselleştirme; satış için fiziksel ürün fotosu gerekir). |
| BOM / maliyet / tedarik | 🟢 **Hazır** | Gerçek malzeme + TR tedarik + fiyat. |

> **Net cevap (PCB test edildi mi?):** **Hayır.** Kart yazılımda tasarlandı ve tasarım kuralı
> kontrolünü (DRC) geçti, ancak **fiziksel olarak üretilmedi ve test edilmedi.** Gerçek ürün için
> önce tasarım inceleme bulguları düzeltilmeli, prototip bastırılmalı ve **bring-up testi** yapılmalı.
> Bu dosya tam olarak bu yolu tanımlar.

---

## 1) Sistem mimarisi (gerçek ürün)

```
 [Patternler .thr]  → (Sandify/Dune Weaver: .thr→G-code) →  ┌────────────────────┐
                                                            │ ESP32 + FluidNC    │→ TMC2209 ×2 → NEMA17 θ, ρ
 Web/uygulama (opsiyonel Raspberry Pi Zero 2 W,             │ (hareket, WebUI,   │→ WS2812B LED (WLED/DW)
 Dune Weaver app: desen kütüphanesi, LED senk, zamanlama)   │  SD'den G-code)    │→ endstop (θ home)
                                                            └────────────────────┘
                                                                 12V güç + buck 5V
```

**Mimari kararlar (2 seçenek):**
- **A — Sade (önerilen başlangıç):** ESP32 + **FluidNC** tek başına. Desenler offline `.thr→G-code`
  çevrilir, **SD karta** konur veya WebUI'dan gönderilir. Pi yok → daha ucuz, daha az parça.
- **B — Tam deneyim:** A + **Raspberry Pi Zero 2 W** üzerinde **Dune Weaver** uygulaması
  (.thr kütüphanesi, canlı önizleme, LED modları, zamanlama). +~500 ₺, daha iyi kullanıcı deneyimi.

> Önerimiz: **EVT/DVT'de A** (riski azalt), satışa hazır üründe **B** (UX için).

---

## 2) Entegrasyon haritası — ne nereye, nasıl bağlanır

| Kart konnektörü | Bağlanır | Kablo / not |
|---|---|---|
| **J1 (12V giriş)** | 12V SMPS | Sigorta + ters polarite koruması (bkz. PCB inceleme) |
| **J2 (θ motor, 4p)** | NEMA17 θ (dönen kol tahriki) | gövde içi sabit |
| **J3 (ρ motor, 4p)** | NEMA17 ρ → **slip ring** → dönen koldaki motor | 4 bobin kablosu kapsül slip ring'den |
| **J4 (LED, 3p: 5V/DIN/GND)** | WS2812B halka | DIN'e **level shifter** (3.3→5V) gerekir (inceleme) |
| **J5 (endstop, 3p)** | θ home opto/mikro switch | dönen tablada referans |
| BK1 buck | 12V→5V | ESP32 + LED + sürücü VIO |
| θ motor şasiye, ρ motor kol ucuna | mekanizma (`montaj.md` §4) | M3, slip ring kablolama |

Fiziksel yerleşim: kontrol kartı **drum içi alüminyum şasiye** (4× M3 standoff), 12V SMPS şasi altına,
slip ring şasi merkezine, LED halka rim iç kenarına. (Detay: `montaj.md`, `montaj_patlatma.png`.)

---

## 3) Üretim akışı — kim, neyi, nasıl üretir

| # | Parça | Proses | Üretici (TR) | DFM notu |
|---|---|---|---|---|
| 1 | Drum gövde + rim | CNC kesim + ceviz kaplama + lake | yerel CNC ahşap/mobilya atölyesi | bükme kontrplak veya istif halka; toleranslar montaj sheet'te |
| 2 | Ayaklar (4) | torna + 8° eğimli plaka | ahşap torna / hazır mobilya ayağı | açı plakadan gelir, elde verilmez |
| 3 | Temperli cam Ø552×6 | kesim + temper + rodaj | yerel temperli cam imalatçısı | low-iron opsiyon |
| 4 | Alüminyum şasi + kol | lazer kesim 6082 | sac/alüminyum lazer atölyesi | DXF kesim dosyaları hazırlanmalı (yapılacak) |
| 5 | **Kontrol kartı (PCB)** | PCB üretim + **SMT dizgi** | **JLCPCB/PCBWay** (dizgi dahil) veya yurtiçi | Gerber+BOM+CPL hazır; **önce inceleme düzeltmeleri** |
| 6 | Final montaj + kablolama + kalibrasyon + QA | manuel | kendi montaj hattın | test planı §6 |

---

## 4) NPI aşamaları — ilk satılabilir üniteye yol

| Aşama | Amaç | Çıktı | Süre (tahmini) | Maliyet |
|---|---|---|---|---|
| **0 · Tasarım dondurma** | İnceleme bulgularını düzelt (PCB, mekanik) | Rev-B Gerber, DXF, BOM | 1–2 hafta | düşük (mühendislik) |
| **1 · EVT** (Engineering) | İlk fonksiyon: 1 PCB bastır+dizgi, bread-board mekanizma, FluidNC bring-up | Çalışan 1 ünite (estetik değil) | 3–4 hafta | ~PCB 5'li + parçalar ~15k ₺ |
| **2 · DVT** (Design Verif.) | Estetik gövde + kalibrasyon + 24h burn-in + desen testi | Sunulabilir prototip | 3–4 hafta | ~1 ünite tam BOM |
| **3 · PVT** (Production) | Küçük seri (10–20), montaj talimatı, QA prosedürü | Satılabilir ürün + süreç | 4–6 hafta | seri BOM × adet |
| **4 · Üretim** | Sürekli üretim | — | — | — |

---

## 5) Test ve doğrulama planı

**5.1 PCB bring-up (kart geldiğinde, motor BAĞLAMADAN):**
1. Görsel + kısa devre kontrolü (multimetre: 12V–GND, 5V–GND direnç).
2. Güç ver, **5V rayını ölç** (4.9–5.1V), ESP32 ısınma yok.
3. ESP32 flash (FluidNC), seri konsol açılıyor mu.
4. TMC2209 UART **adres okuma** (FluidNC `$Stepper/...` — her iki sürücü ayrı adres yanıt vermeli).
5. WS2812: tek LED test (level shifter doğrulaması).

**5.2 Hareket:**
6. Motorları bağla, akım ayarı (TMC2209 ~0.6–0.9A), θ tam tur (kayma yok), ρ menzil/endstop.
7. Bilye sürükleme: mıknatıs gücü vs hız (kostik/kayıp testi).

**5.3 Sistem:**
8. Tam desen çiz (Atatürk imza + spiral), 24h **burn-in** (ısınma, gürültü, kaçırma).
9. **Güvenlik:** 12V SMPS CE'li, sigorta, topraklama, sıcaklık < sınır; cam kenar emniyeti.

---

## 6) Maliyet (COGS) ve hedef satış fiyatı

| | Prototip (1 ad) | Seri (50+, parça başı) |
|---|---|---|
| Malzeme (BOM) | ~10.800 ₺ | ~6.100 ₺ |
| İşçilik/montaj | +2.500–4.000 | +1.200 |
| (Tam deneyim) + Raspberry Pi Zero 2 W | — | +500 |
| **COGS** | **~13.500–15.000 ₺** | **~7.800 ₺ (~$230)** |

**Fiyatlandırma (profesyonel marj analizi):**
- Sağlıklı donanım perakende marjı: satış ≈ **2.5–3× COGS** (garanti, iade, pazarlama, kanal payı dahil).
- Seri COGS ~7.800 ₺ → **hedef MSRP ≈ 19.900–23.900 ₺ ($590–700)**.
- **Önerilen liste fiyatı: 21.900 ₺ (~$650)** — benzer ürün ($699) ile rekabetçi, ~%64 brüt marj.
- Lansman/erken kuş: 17.900 ₺; bayi/kanal: liste − %30.

> Not: işçilik + overhead + garanti rezervi (ünite başı ~%8) + iade (~%3) fiyata içkindir.
> Marj, montaj kalitesi/marka/hazır desen kütüphanesinde korunur (donanım kolay kopyalanır).

---

## 7) Risk kaydı (öne çıkanlar)

| Risk | Etki | Önlem |
|---|---|---|
| **PCB ilk dönüşte çalışmaz** | yüksek | inceleme düzeltmeleri + 5'li bastır (yedek), bring-up planı |
| WS2812 3.3V data güvenilmez | orta | level shifter (74AHCT125) — Rev-B |
| TMC2209 UART adres çakışması | orta | MS1/MS2 ayrı adres — Rev-B |
| Slip ring kontak/gürültü | orta | kaliteli kapsül slip ring, ρ akımı düşük tut |
| Mıknatıs bilyeyi kaçırır (hız) | orta | hız limiti + mıknatıs/hava aralığı testi |
| Cam ağırlığı/emniyet | orta | temperli + rodaj + mıknatıslı modül SF 5.2× |
| Tedarik/kur dalgalanması | orta | döviz endeksli kalemler için stok/sözleşme |

---

## 8) İlgili dosyalar
- `PCB_inceleme.md` — dürüst elektriksel inceleme + üretim öncesi düzeltmeler
- `../../firmware/fluidnc_config.yaml` + `../../firmware/README.md` — firmware mimarisi/config
- `BOM_uretim.md` · `montaj.md` · `montaj_sheet.svg` · `montaj_patlatma.png`
- `../../hardware/pcb/` — KiCad tasarımı, Gerber, STEP

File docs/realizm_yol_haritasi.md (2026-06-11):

# Gerçeklik Yol Haritası — sonraki aşamalar

Mevcut durum: kod-tabanlı Blender/Cycles render (stüdyo HDRI + gerçek PBR doku) + WebGL simülasyon.
"Gerçekten gerçek" hisse ulaşmak için aşamalar (etkili → maliyetli sırayla):

## 1) Kum oluğu = gerçek geometri (en yüksek etki)
Şu an desen, kumun üstünde ince bir **çizgi/tüp**. Gerçekte bilye kumda **oluk açar**:
çukur + iki yanda kabarma (berm) + grenli gölge.
- **Render:** kumu yüksek alt-bölmeli mesh yap; `.thr` yolundan bir **yükseklik haritası (heightmap)**
  üret (yol boyunca Gauss çukur + kenar kabarma) → **displacement** modifier. Cycles adaptive subdiv.
  Bilye geçtikçe gerçek gölge/AO oluşur → fotoğraf gibi.
- **Sim (WebGL):** aynı heightmap'i bir doku olarak kuma uygula (normal/parallax); bilye ilerledikçe
  heightmap'e çukur "boya" (render-to-texture) → canlı oyulan kum.

## 2) Mekanizmanın görünür çalışması
Bilye tek başına yörünge izliyor; gerçekte **dönen kol + taşıyıcı + mıknatıs** kumun altında hareket eder.
- θ-ρ kinematiğini hesapla: her kare bilyenin (theta,rho)'suna göre kolu döndür, taşıyıcıyı kaydır,
  mıknatısı bilyenin tam altına koy. Hem sim hem video bunu göstersin → mekanizma inandırıcı olur.

## 3) Render kalitesi (foto-kalibrasyon)
- **Sample** 384 → 1024+, **DOF/bokeh**, hafif **film grain + kromatik** (gerçek lens hissi).
- **Kostik:** cam → kum ışık kırılması (Cycles caustics / MNEE) → cam gerçekçiliği büyük sıçrar.
- **Gerçek referans:** benzer ürün fotoğraflarıyla ışık/poz eşle.

## 4) Malzeme doğrulama (ölçülü PBR)
- Gerçek **ceviz, kum, cam** örneklerini tarayıp (polarized foto / fotogrametri) doğru
  albedo–roughness–normal çıkar. Tahmini değerler yerine ölçülmüş → "CG kokusu" gider.
- Kum: gerçek granül boyutu/rengi (kuvars vs silis), nemli/kuru sheen.

## 5) WebGL simülasyon gerçekçiliği
- Gerçek **HDRI environment** (zaten studio.hdr) + **SSAO** + **yumuşak gölge** + **DOF**.
- Kum **parallax/normal** shader; oluk için (1)'deki heightmap.
- Alternatif: gerçekçilik kritikse, sim yerine **pre-rendered döngü video** (Cycles) göster;
  etkileşim için ayrı basit sim. (Gerçek zamanlı asla TV-reklam fotoğraf-gerçekçiliğinde olmaz.)

## 6) Fiziksel prototip → gerçek foto/video (altın standart)
CAD render hiçbir zaman %100 değil. **Gerçek prototip** üretip (BOM + montaj hazır) gerçek
fotoğraf/video çekmek, en inandırıcı "reklam" malzemesidir. Render'lar ön-görselleştirme;
satış görseli için fiziksel ürün şart.

## Öncelik önerisi
1 (oluk geometrisi) + 2 (mekanizma hareketi) → görselin "gerçek cihaz" hissini en çok artıran ikisi.
Sonra 3–4 (render/materyal kalibrasyonu). Nihai: 6 (gerçek prototip).

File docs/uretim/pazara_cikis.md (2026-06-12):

# Pazara Çıkış (GTM) + Companion Uygulama UX

Premium tasarım objesini nasıl konumlandırıp satarız + "akıllı obje" deneyimini tanımlayan
uygulama konsepti. Global donanım/tasarım şirketi yaklaşımı.

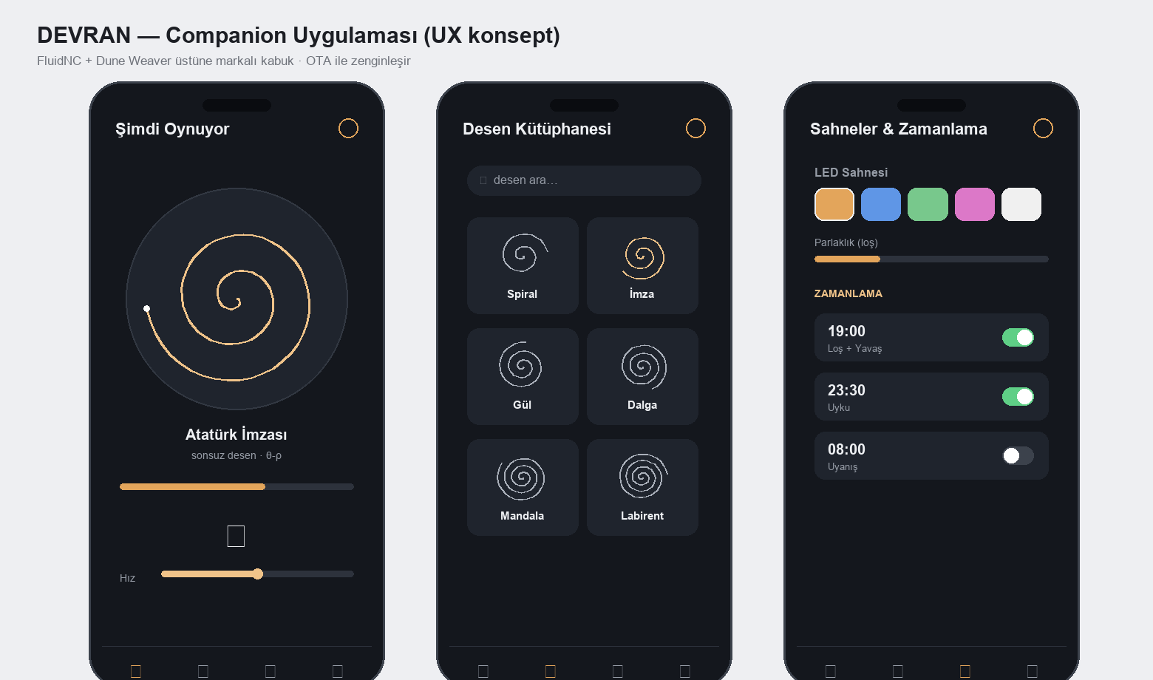
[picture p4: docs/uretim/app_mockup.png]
uygulama UX


## 1) Konumlandırma
**DEVRAN** = *yaşayan sanat eseri* — dekoratif obje + sakinleştirici hareket + ışık.
Hedef his: Teenage Engineering'in tasarım disiplini + Sisyphus'un sükûneti, **yerli üretim** hikâyesiyle.

- **Birincil kitle:** tasarım-bilinçli premium ev sahibi, koleksiyoner, hediye alıcısı.
- **İkincil:** otel/lobi/ofis (kurumsal), galeri/konsept mağaza.
- **Mesaj:** "Kumun üstünde kendiliğinden çizilen, hiç tekrarlamayan sanat."

## 2) Kanal stratejisi
| Kanal | Rol |
|---|---|
| **Kickstarter / crowdfunding** | donanımda standart lansman — talep doğrula + ön finansman + topluluk |
| **D2C web (ön-sipariş + checkout)** | ana marj kanalı; mevcut site → e-ticaret'e |
| **Tasarım perakende / galeri / konsept mağaza** | premium konumlandırma + görünürlük |
| **Kurumsal/hediye** | yüksek sepet, B2B |

## 3) Fiyat katmanları
| Katman | İçerik | Fiyat (hedef) |
|---|---|---|
| Early bird (Kickstarter) | ilk parti, indirimli | ~17.900 ₺ / ~$530 |
| Standart | ceviz + temperli cam | **21.900 ₺ / ~$650** |
| Signature/limited | özel finiş + plaka + ekstra desen | ~28.900 ₺ / ~$850 |
| (Aksesuar) | ekstra desen paketi, özel kum | düşük marj-yükseltici |

Seri COGS ~7.800 ₺ → standart katmanda ~%64 brüt marj. İade rezervi (~%3) + garanti (~%8) fiyata içkin.

## 4) Lansman zaman çizelgesi (kaba)
1. **Prototip + gerçek foto/film** (ön koşul — render değil)
2. **Kitle ön-ısıtma** (landing + e-posta listesi + sosyal teaser)
3. **Kickstarter** (30 gün) — hedef X adet
4. **Üretim (PVT→seri)** + **CE/FCC** paralel
5. **Teslim + D2C açılışı** + perakende/galeri görüşmeleri
6. **Topluluk deseni** + sürüm güncellemeleri

## 5) Ölçütler (global pro takip eder)
Dönüşüm oranı, CAC, AOV, iade %, NPS, üretim verimi (yield), birim marj, Kickstarter dönüşümü.

---

## 6) Companion uygulama UX (konsept)
"Akıllı obje" deneyimi — Sisyphus/Dune Weaver seviyesinde, marka diliyle:

| Ekran | İşlev |
|---|---|
| **Şimdi oynuyor** | canlı desen önizleme + ilerleme, hız, LED sahnesi, oynat/duraklat |
| **Desen kütüphanesi** | yerleşik + topluluk `.thr`; favori, kategori |
| **Sahneler** | LED modu (idle/playing/scheduled), renk, parlaklık |
| **Zamanlama** | "akşam 19:00 loş + yavaş", uyku/uyanma |
| **Cihaz** | Wi-Fi, OTA güncelleme, kalibrasyon, durum/sağlık |
| **Stüdyo** | görüntü/yazı → desen (image→.thr), paylaş |

**İlkeler:** sessiz/sakin arayüz, premium tipografi, tek elle erişim, OTA ile zamanla zenginleşen
özellikler (yazılım değeri). Teknik altyapı **FluidNC + Dune Weaver** üstüne markalı bir kabuk.

> Ekosistem = donanım marjı + **yazılım/desen pazarı** (tekrar gelir + topluluk = savunma hattı,
> çünkü donanım kolay kopyalanır).

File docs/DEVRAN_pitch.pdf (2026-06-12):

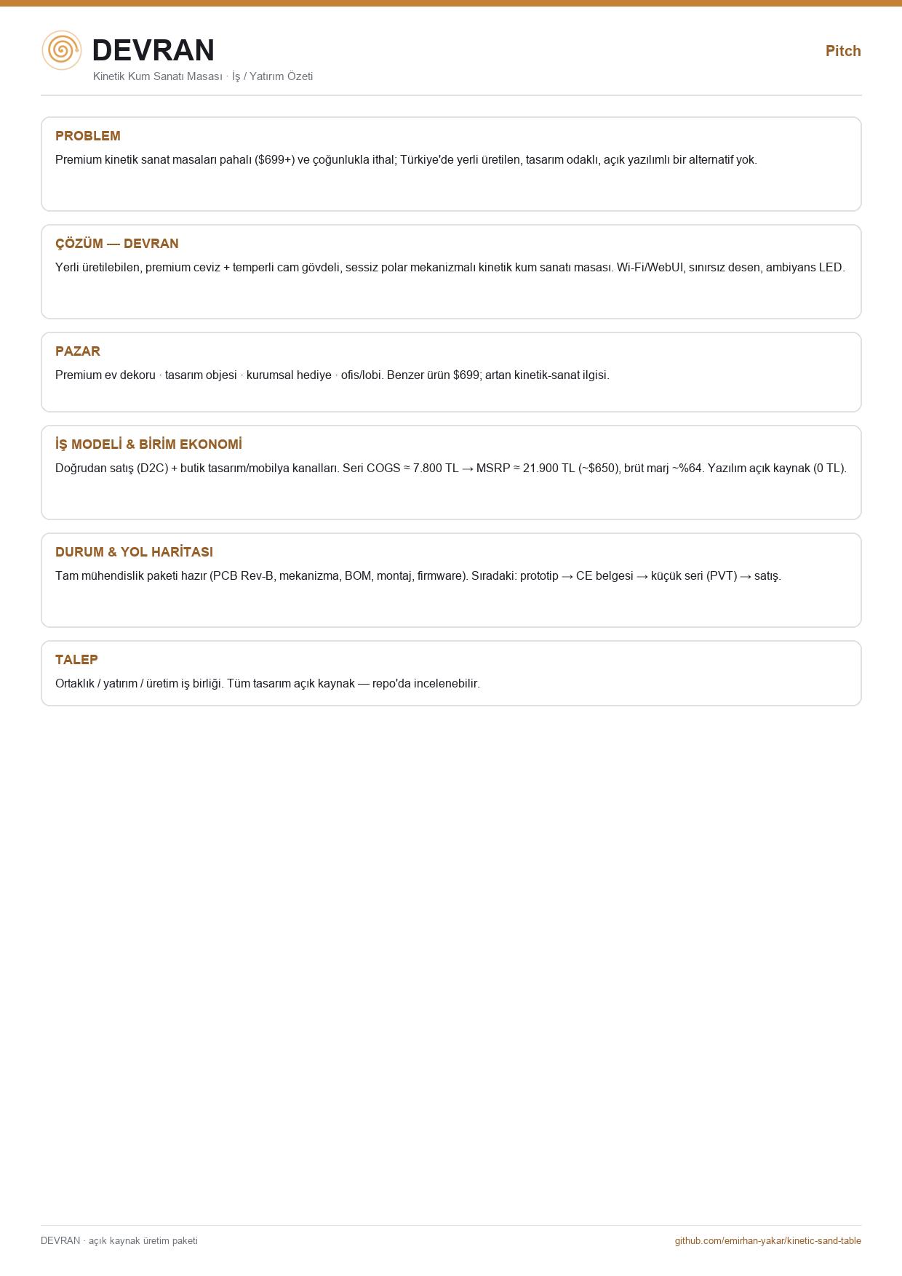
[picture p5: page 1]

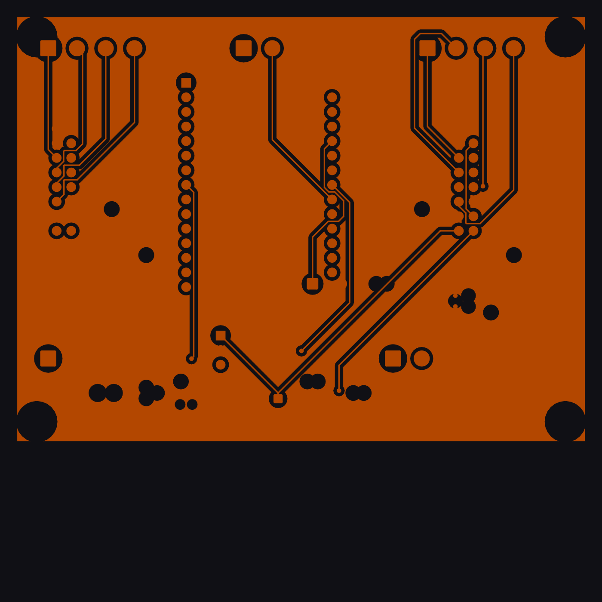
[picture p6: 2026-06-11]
hardware/pcb/final/plots/final-B_Cu-groundplane.png

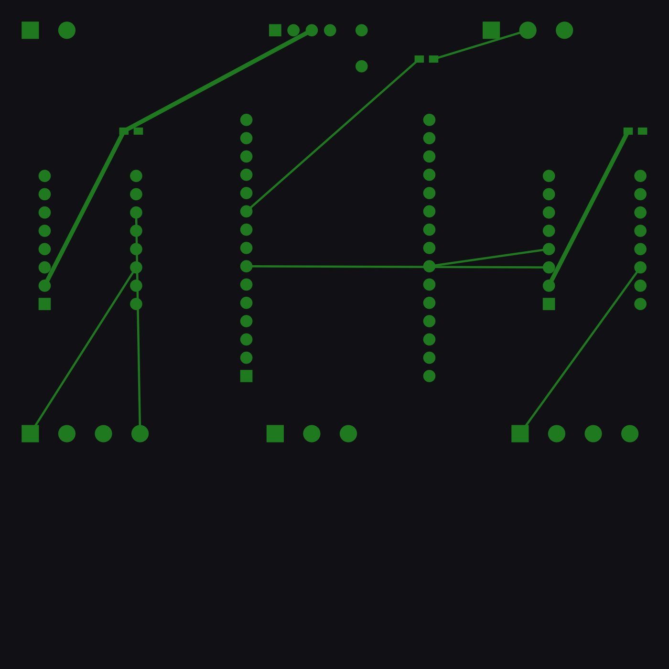
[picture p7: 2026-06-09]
hardware/pcb/plots/top_cu.svg.png

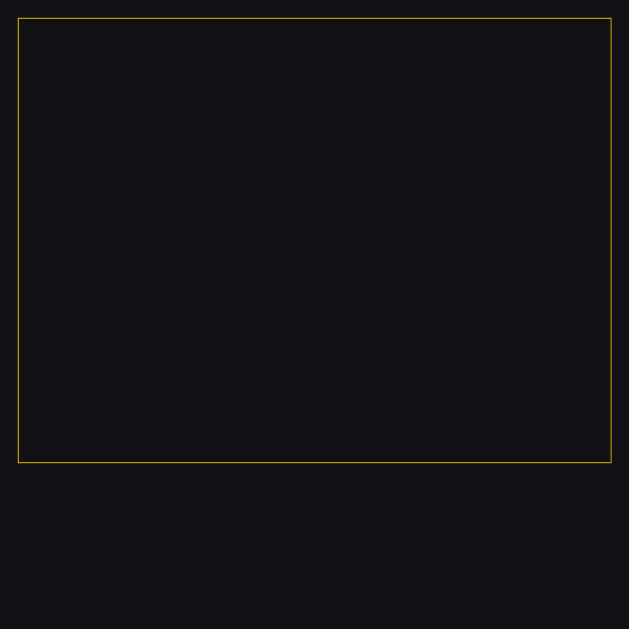
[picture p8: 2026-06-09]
hardware/pcb/plots/edge.svg.png

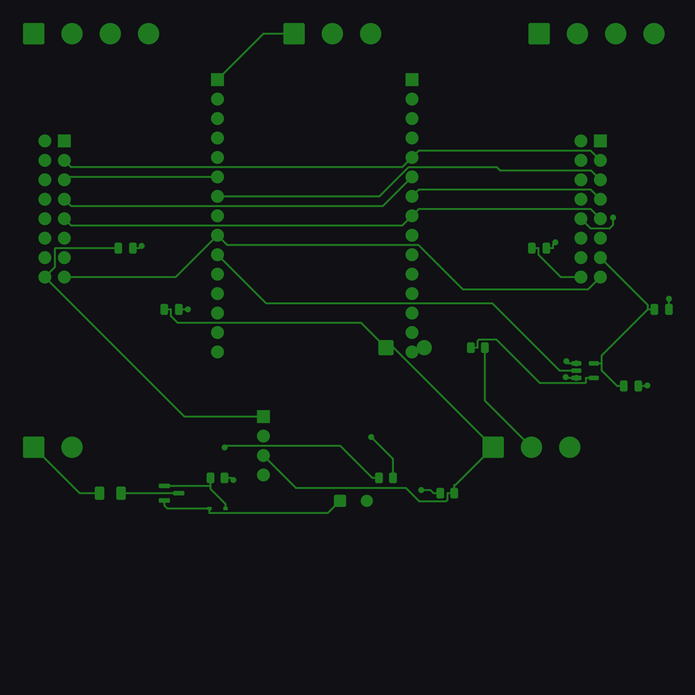
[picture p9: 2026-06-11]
hardware/pcb/final/plots/final-F_Cu-routed.png

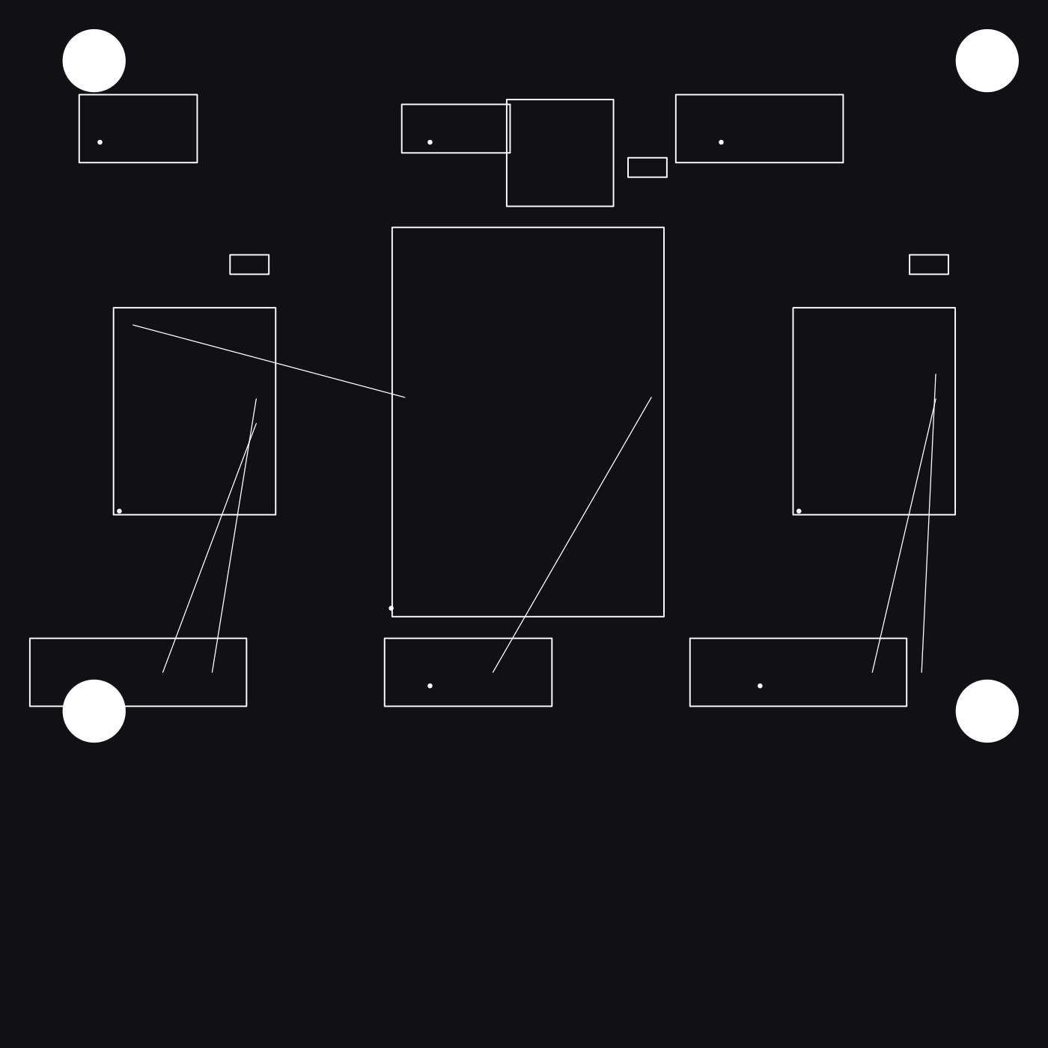
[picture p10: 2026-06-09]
hardware/pcb/plots/top_silk.svg.png

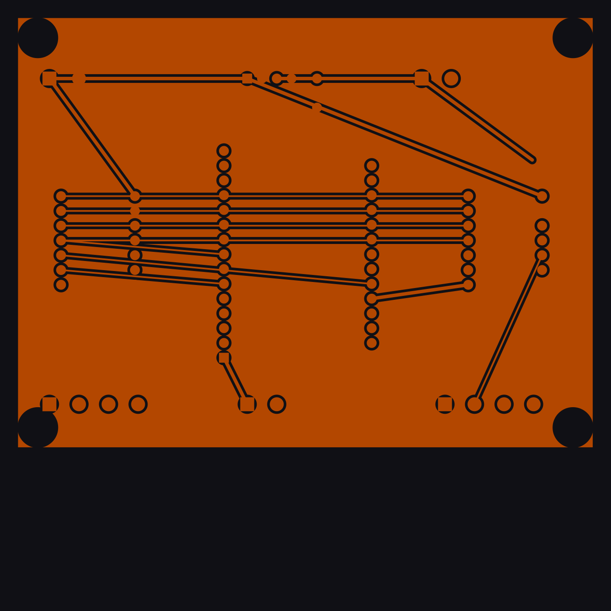
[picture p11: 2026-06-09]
hardware/pcb/plots/bot_cu.svg.png

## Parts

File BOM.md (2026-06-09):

# Malzeme Listesi (BOM) — Polar Kum Masası Ø60 cm

Fiyatlar Haziran 2026 yaklaşık yurt içi perakende; ₺ kuru oynaktır, USD karşılığı
yön vermek içindir. Linkler kategori/tedarikçi düzeyindedir (model seçimini
ölçüye göre yaparsın).

## 1) Hareket / mekanik
| Parça | Adet | Not | Tedarik | ~₺ |
|---|---|---|---|---|
| NEMA 17 step motor (1.5–1.8A, 42mm) | 2 | θ ve ρ eksenleri | [Robotistan](https://www.robotistan.com), [Motorobit](https://www.motorobit.com) | 500–700 |
| Lazy-susan / turntable rulman (Ø100–150mm) | 1 | dönen kol tablası | rulmancı / Hepsiburada | 150–300 |
| GT2 6mm kayış (5m) + 20T pulley (2) + F623 idler (4) | 1 set | θ büyük pulley + ρ kayış | [Robotistan](https://www.robotistan.com) | 250–400 |
| MGN12 lineer ray + araba (250–300mm) | 1 | ρ ekseni (kol içi) | Robotistan / Aliexpress | 350–600 |
| **6+ kanallı slip ring (kapsül, 12V)** | 1 | dönen kola ρ motor kablosu | [Robotistan](https://www.robotistan.com)/Aliexpress | 250–450 |
| 3D baskı parçalar (PETG): kol, motor yatakları, mıknatıs taşıyıcı | — | `sand_table.scad`'den STL | kendi yazıcın / baskı servisi | 200–400 |

## 2) Mıknatıs & bilye
| Parça | Adet | Not | Tedarik | ~₺ |
|---|---|---|---|---|
| N52 neodyum mıknatıs (Ø15–20mm) | 1–3 | taşıyıcıda | mıknatıs satıcıları | 100–250 |
| Çelik bilye (krom çelik, Ø10–15mm) | 1 | kum üstünde | rulmancı | 30–80 |
| İnce dekoratif/kuvars kum | 1–2 kg | yüzey | hobi/akvaryum | 50–150 |

## 3) Elektronik / beyin
| Parça | Adet | Not | Tedarik | ~₺ |
|---|---|---|---|---|
| ESP32 DevKit (WROOM-32) | 1 | Dune Weaver firmware | [Robotistan](https://www.robotistan.com), [Direnç.net](https://www.direnc.net) | 150–250 |
| TMC2209 step sürücü | 2 | sessiz çalışma için ideal | Robotistan | 300–400 |
| **PROTOTİP alternatifi:** MKS DLC32 / BTT kontrol kartı (ESP32 dahili) | 1 | sürücü yuvalı, kablolama kolay | Robotistan | 700–1200 |

## 4) LED aydınlatma
| Parça | Adet | Not | Tedarik | ~₺ |
|---|---|---|---|---|
| WS2812B / SK6812 adreslenebilir şerit (60 LED/m, ~2m) | 1 | kenar halka | **[Samm Teknoloji](https://www.samm.com)**, **[Direnç.net](https://www.direnc.net)**, **[LED Pazarı](https://www.ledpazari.com)**, Robotistan | 150–350 |
| 1000µF kondansatör + 330Ω direnç (LED hat koruması) | — | std. WS2812 önerisi | Direnç.net | 20 |

> Toptan/seri için: **LCSC** veya **Aliexpress** (WS2812B 5m makara çok daha ucuz).

## 5) Güç
| Parça | Adet | Not | Tedarik | ~₺ |
|---|---|---|---|---|
| 12V 5–10A SMPS / masaüstü adaptör | 1 | motorlar + LED | elektronik tedarikçi | 250–450 |
| Buck konvertör 12V→5V (LED + ESP32) | 1 | 3–5A | Robotistan | 60–120 |

## 6) Gövde / kabin
| Parça | Adet | Not | Tedarik | ~₺ |
|---|---|---|---|---|
| Temperli cam üst (Ø60cm, 5–6mm, kenar rodajlı) | 1 | yüzey | yerel camcı | 600–1200 |
| MDF/kontrplak gövde + alt taban (CNC/lazer kesim) | 1 | kabin | marangoz / lazer atölye | 800–1800 |
| Ahşap kaplama / boya / ayaklar / vida-somun seti | — | bitirme | — | 400–800 |

## Toplam maliyet
| Senaryo | Yaklaşık |
|---|---|
| **Tek-adet prototip** (V-slot yerine MGN12, hazır kart) | **~6.000–10.000 ₺ (≈ $180–300)** |
| **Seri (50+ adet, özel PCB + toplu alım)** | parça başı **~3.500–5.500 ₺** |
| Karşılaştırma: Nikolatoy satış fiyatı | $699 (≈ 22.000+ ₺) |

**Yazılım maliyeti: 0 ₺** — Dune Weaver firmware + Sandify desen üreteci açık kaynak.

> Not: Ø60 yuvarlak + slip ring versiyonu kareye göre biraz daha pahalı ama premium
> segment satış fiyatını fazlasıyla karşılar. Marj asıl olarak montaj kalitesi,
> sessizlik, marka ve hazır desen kütüphanesinde.

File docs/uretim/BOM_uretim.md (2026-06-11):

# Üretim BOM'u — Kinetik Kum Masası (Ø600, ayaklı sehpa)

Gerçek malzemeler, Türkiye tedarik kaynakları ve **gerçekçi 2026 fiyatları** (₺, KDV dahil yaklaşık).
Tek-adet prototip içindir; seri için "Seri" sütunu (50+ adet, toplu alım + kendi PCB dizgi).
Geometri/açı/PCD değerleri için `montaj.md` ve `montaj_sheet.svg`.

> Kur notu: ₺ oynaktır; elektronik/mıknatıs kalemleri büyük ölçüde döviz endeksli.
> Fiyatlar Haziran 2026 perakende seviyesidir.

---

## 1) Gövde & ahşap (marangoz / CNC ahşap atölyesi)
| Parça | Gerçek malzeme / spec | Adet | Tedarik (TR) | Birim ₺ | Toplam ₺ | Seri ₺ |
|---|---|---|---|---|---|---|
| Drum gövde silindir | **18 mm huş kontrplak (bükme) veya istif MDF halka**, dış Ø600 × H150, et 18 | 1 | yerel **CNC ahşap/mobilya atölyesi** (Siteler-Ankara, Modoko/Masko-İst.) | 1.600 | 1.600 | 900 |
| Ceviz kaplama + cila | **doğal ceviz kaplama (0.6mm)** + su bazlı mat lake | 1 set | marangoz / kaplama atölyesi | 700 | 700 | 350 |
| Üst çerçeve (rim) | ceviz masif/kaplama, Ø600/iç Ø520, cam rabbet + mıknatıs cebi | 1 | CNC atölye | 450 | 450 | 250 |
| Ayaklar (4) | **masif ceviz/gürgen konik ayak 320mm**, 8° eğimli plakalı — veya hazır mid-century ayak seti | 1 set | **mobilya ayağı satıcıları** / ahşap torna atölyesi | 900 | 900 | 500 |
| Kum yatağı tepsisi | 4mm MDF/alüminyum, Ø520 (mıknatıslı üst modül tabanı) | 1 | CNC / lazer | 250 | 250 | 150 |
| **Ara toplam ahşap** | | | | | **3.900** | 2.150 |

## 2) Cam (temperli cam imalatçısı)
| Parça | Spec | Adet | Tedarik | Birim ₺ | Toplam ₺ | Seri ₺ |
|---|---|---|---|---|---|---|
| Üst cam | **temperli cam Ø552 × 6mm, kenar rodajlı** (ops. low-iron ekstra şeffaf) | 1 | yerel **temperli cam imalatçısı** (her ilde) | 850 | 850 | 600 |

## 3) Hareket mekaniği (elektronik + lazer kesim + rulmancı)
| Parça | Gerçek malzeme / spec | Adet | Tedarik (TR) | Birim ₺ | Toplam ₺ | Seri ₺ |
|---|---|---|---|---|---|---|
| NEMA17 step motor | 42×42, 1.5–1.8 A, 1.8° | 2 | **Robotistan / Motorobit** | 420 | 840 | 320/ad |
| Lazy-susan / turntable rulman | Ø150 döner tabla rulmanı (θ ekseni) | 1 | rulmancı / Hepsiburada | 220 | 220 | 150 |
| MGN12H lineer ray + araba | 300 mm (ρ ekseni) | 1 | Robotistan / Aliexpress | 520 | 520 | 380 |
| GT2 kayış 5m + 20T pulley ×2 + F623 idler ×4 | 6mm kayış | 1 set | Robotistan | 320 | 320 | 220 |
| **Slip ring** (kapsül) | 6–12 kanal, 12V/2A — dönen ρ motoru kablosu | 1 | Robotistan / Aliexpress | 380 | 380 | 280 |
| Mekanizma şasi plakası | **alüminyum 6082 / 5754, 4mm lazer kesim**, Ø520 | 1 | **sac/alüminyum lazer kesim atölyesi** | 350 | 350 | 180 |
| Dönen kol (arm) | alüminyum 6082 5mm lazer kesim | 1 | lazer atölye | 180 | 180 | 90 |
| Taşıyıcı + mıknatıs yuvası | 3D baskı PETG veya alüminyum | 1 | kendi baskı / lazer | 120 | 120 | 60 |
| **Ara toplam mekanik** | | | | | **2.930** | 1.680 |

## 4) Mıknatıslar & bilye (neodyum mıknatıs satıcıları)
| Parça | Spec | Adet | Tedarik | Birim ₺ | Toplam ₺ | Seri ₺ |
|---|---|---|---|---|---|---|
| Bilye sürücü mıknatıs | **N52 neodyum Ø20×10mm** (~9 kgf) | 1 | mıknatıs satıcıları | 140 | 140 | 90 |
| Üst modül tutucu mıknatıs | **N52 Ø20×3mm** (~2.7 kgf) | 8 | mıknatıs satıcıları | 35 | 280 | 22/ad |
| Karşı çelik plaka (mıknatıs için) | **DKP saç 1.5mm**, Ø22 disk | 8 | lazer kesim / sac | 12 | 96 | 6/ad |
| Çelik bilye | **AISI 420 / krom çelik Ø12mm** | 1 | rulmancı | 45 | 45 | 25 |
| **Ara toplam mıknatıs** | | | | | **561** | 360 |

## 5) Aydınlatma & güç
| Parça | Spec | Adet | Tedarik | Birim ₺ | Toplam ₺ | Seri ₺ |
|---|---|---|---|---|---|---|
| WS2812B adreslenebilir LED şerit | 60 LED/m, ~2 m (kenar halka) | 1 | **Samm Teknoloji / Direnç.net / LED Pazarı** | 280 | 280 | 180 |
| 12V SMPS güç kaynağı | 12V 6A (72W) | 1 | elektronik tedarikçi | 360 | 360 | 250 |
| Buck konvertör 12→5V | 3–5A (LED + lojik) | 1 | Robotistan | 90 | 90 | 55 |
| **Ara toplam güç/LED** | | | | | **730** | 485 |

## 6) Kontrol kartı (bizim tasarım — `hardware/pcb/`)
| Parça | Spec | Adet | Tedarik | Birim ₺ | Toplam ₺ | Seri ₺ |
|---|---|---|---|---|---|---|
| Kontrol PCB | ESP32 + 2× TMC2209 + WS2812 + güç (`controller.kicad_pcb`) | 1 | **JLCPCB/PCBWay** (Çin, 5 adet min) veya yurtiçi PCB | 450 | 450 | 90/ad |
| ESP32-DevKitC / TMC2209 (prototip modül) | hazır modül (PCB header'a) | 1 set | Robotistan | 720 | 720 | dizgi: 350 |
| **Ara toplam kart** | | | | | **1.170** | 440 |

## 7) Bağlantı elemanları & sarf
| Parça | Spec | Adet | Tedarik | Birim ₺ | Toplam ₺ | Seri ₺ |
|---|---|---|---|---|---|---|
| Gömme dişli (threaded insert) | M4 & M6 ahşap için (ısı/burgu) | ~20 | hırdavat | 6 | 120 | 70 |
| Paslanmaz vida/civata seti | M3×8, M4×16, M5×40, M6×30 + somun/pul | 1 set | hırdavat | 200 | 200 | 120 |
| Pirinç standoff (M4) | mekanizma plakası ayağı | 8 | Robotistan | 12 | 96 | 60 |
| İnce kuvars/silis kum | 0.1–0.3mm, ~1.5 kg | 1 | hobi / dökümhane | 90 | 90 | 50 |
| Kablo, klemens, kablo kanalı, ayak keçesi | — | 1 set | hırdavat | 180 | 180 | 110 |
| **Ara toplam sarf** | | | | | **686** | 410 |

---

## TOPLAM
| | Prototip (1 ad.) | Seri (≥50 ad., parça başı) |
|---|---|---|
| Ahşap | 3.900 | 2.150 |
| Cam | 850 | 600 |
| Mekanik | 2.930 | 1.680 |
| Mıknatıs/bilye | 561 | 360 |
| Güç/LED | 730 | 485 |
| Kontrol kartı | 1.170 | 440 |
| Sarf/bağlantı | 686 | 410 |
| **MALZEME TOPLAM** | **≈ 10.800 ₺** (~$320) | **≈ 6.100 ₺** (~$180) |
| İşçilik/montaj (tahmini) | +2.500–4.000 | +1.200 |
| **GERÇEKÇİ MALİYET** | **≈ 13.500–15.000 ₺** | **≈ 7.300 ₺** |

Yazılım: **0 ₺** (Dune Weaver firmware + Sandify/desen araçları açık kaynak, `firmware/`).

**Satış karşılaştırması:** Nikolatoy $699 (≈ 23.000+ ₺). Seri maliyet/satış oranı **~%32** → sağlıklı marj.

---

## Tedarik özeti — "nereden"
- **Elektronik/motor/ray/slip ring:** robotistan.com, motorobit.com, direnc.net
- **LED (WS2812B):** samm.com, direnc.net, ledpazari.com — toplu: LCSC/Aliexpress
- **Mıknatıs (N52):** yurtiçi neodyum mıknatıs satıcıları (online)
- **Ahşap gövde/CNC + ayak:** yerel CNC ahşap / mobilya atölyesi (Siteler-Ankara, Modoko/Masko-İstanbul, İzmir Karabağlar)
- **Temperli cam:** yerel temperli cam imalatçısı (rodajlı kesim)
- **Alüminyum lazer kesim (şasi/kol/karşı plaka):** sac-alüminyum lazer kesim atölyesi
- **PCB:** JLCPCB/PCBWay (ucuz, dizgi dahil) veya yurtiçi PCB firmaları (Bursa/İstanbul)
- **Hırdavat/bağlantı/insert:** yerel cıvata-hırdavat

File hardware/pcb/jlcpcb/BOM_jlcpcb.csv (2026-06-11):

Comment | Designator | Footprint | LCSC Part #
330 | R1 | 0805 | C17630
100k | R2 | 0805 | C17407
10k | R3 | 0805 | C17414
1k | R4 | 0805 | C17513
100nF | C2,C3,C5,C7,C8 | 0805 | C49678
74AHCT1G125 | U2 | SOT-23-5 | DOGRULA
AO3401A | Q1 | SOT-23 | C15127
BZT52C10 10V | D1 | SOD-323 | DOGRULA
PTC 3A | F1 | 1206 | DOGRULA

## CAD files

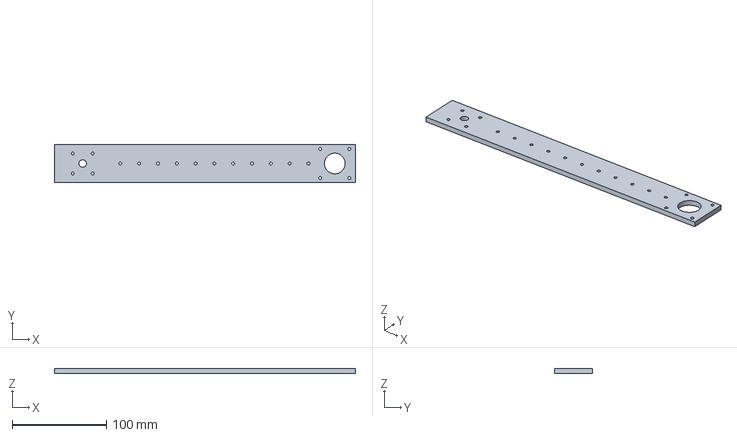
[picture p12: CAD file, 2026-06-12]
docs/uretim/dxf/kol.step
320.0 x 40.0 x 5.00 mm

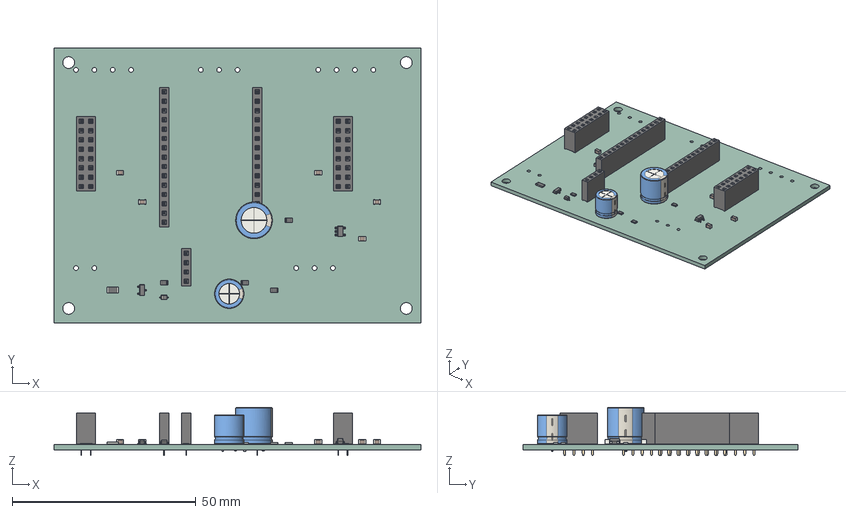
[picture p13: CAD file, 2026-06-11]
hardware/pcb/final/controller.step
100.0 x 75.0 x 13.1 mm
PinSocket_1x15_P2.54mm_Vertical x 2
C_0805_2012Metric x 5
PinSocket_2x08_P2.54mm_Vertical x 2
PinSocket_1x04_P2.54mm_Vertical
R_0805_2012Metric x 4
D_SOD-323
CP_Radial_D8.0mm_P3.50mm
SOT-23-5
Fuse_1206_3216Metric
CP_Radial_D10.0mm_P5.00mm
SOT-23
controller_PCB

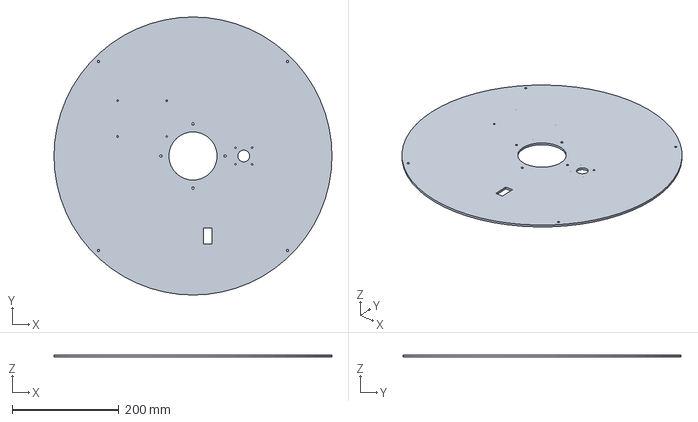
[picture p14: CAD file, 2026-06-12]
docs/uretim/dxf/sasi.step
520.0 x 520.0 x 4.00 mm

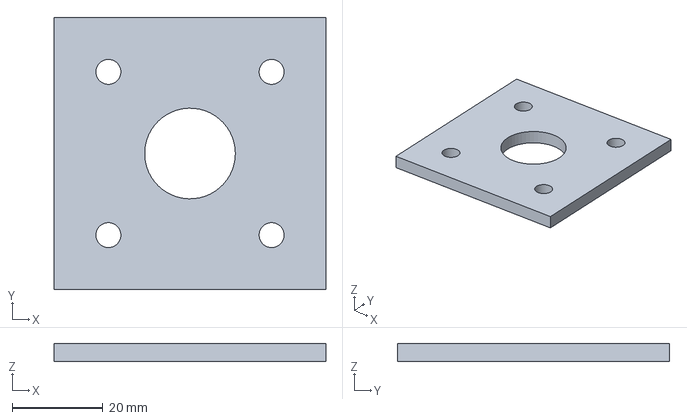
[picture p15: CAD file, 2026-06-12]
docs/uretim/dxf/ayak_plakasi.step
60.0 x 60.0 x 4.00 mm

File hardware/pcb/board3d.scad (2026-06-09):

// ============================================================================
//  Kontrol Karti - 3D dizgi modeli (populated PCB)
//  pcb_gen.py ile ayni yerlesim. OpenSCAD'de Render (F6) -> Export STL.
//  Birim: mm
// ============================================================================
BW = 100; BH = 75; TH = 1.6;        // kart olculeri (pcb_gen.py ile ayni)
$fn = 48;

module pcb() {
    color([0.05,0.35,0.12]) difference() {              // FR4 yesil
        linear_extrude(TH) offset(r=2) offset(r=-2)
            square([BW,BH]);
        for (p=[[4,4],[BW-4,4],[BW-4,BH-4],[4,BH-4]])
            translate([p[0],p[1],-1]) cylinder(d=3.2,h=TH+2);
    }
    // bakir alt GND plane ipucu (ince katman)
    color([0.72,0.45,0.2]) translate([2,2,-0.05]) cube([BW-4,BH-4,0.05]);
}

// --- jenerik dik pin header / modul govdesi ---
module block(x,y,w,d,h,col) translate([x-w/2,y-d/2,TH]) color(col) cube([w,d,h]);
module pinrow(x,y,n,pitch=2.54,horiz=true)
    for(i=[0:n-1]) translate(horiz?[x+i*pitch,y,TH]:[x,y+i*pitch,TH])
        color([0.85,0.75,0.2]) cylinder(d=0.6,h=4);

module esp32()    { block(36+12.7,16+15*2.54/2-1.27, 28,40, 13,[0.1,0.1,0.12]);
                    color([0.8,0.8,0.85]) block(36+12.7,16+38, 16,18,2,[0.8,0.8,0.85]); } // anten
module stepstick(x,y,c){ block(x+6.35,y+8.9, 16,21, 3,[0.15,0.15,0.15]);
                    color([0.6,0.6,0.65]) translate([x+6.35-3,y+8.9,TH+3]) cube([6,6,5],center=true); } // surucu IC + heatsink
module buck(x,y)  block(x+3.8,y, 11,17,4,[0.05,0.05,0.4]);
module term(x,y,n){ block(x+(n-1)*5.08/2,y, n*5.08+2,8,9,[0.1,0.25,0.6]); }  // mavi vidali klemens
module ecap(x,y)  translate([x,y,TH]) color([0.1,0.1,0.12]) cylinder(d=10,h=12);
module smd(x,y)   block(x,y,3,1.6,0.6,[0.1,0.1,0.1]);

module assembly() {
    pcb();
    esp32();
    stepstick(8,26,"th"); stepstick(78,26,"rh");
    buck(40,64);
    term(6,64,2);                 // J1 12V
    term(6,8,4); term(74,8,4);    // J2/J3 motor
    term(70,64,3);                // J4 LED
    term(40,8,3);                 // J5 endstop
    ecap(52,61.5);                // C1
    smd(61,60);                   // R1
    smd(20,50); smd(90,50);       // C2,C3
}
assembly();

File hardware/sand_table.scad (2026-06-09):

// ============================================================================
//  Kinetik Kum Sanatı Masası — Parametrik Model (Polar / Theta-Rho)
//  Hedef: Yuvarlak Ø60 cm sehpa. OpenSCAD'de aç, parametreleri değiştir,
//  Render (F6) -> Export STL. Her ana parça ayrı modül; STL için altta seç.
//  Birim: mm
// ============================================================================

/* [Ana ölçüler] */
TABLE_DIAMETER   = 600;   // cam yüzey çapı
TABLE_HEIGHT     = 380;   // toplam masa yüksekliği (sehpa)
WALL             = 18;    // gövde et kalınlığı (MDF)
GLASS_THICK      = 6;     // temperli cam
SAND_DEPTH       = 8;     // kum tabakası (görsel)
LED_RING_H       = 14;    // LED halka yüksekliği

/* [Mekanizma] */
ARM_LENGTH       = (TABLE_DIAMETER/2) - 30;  // dönen kol uzunluğu (ρ menzili)
ARM_WIDTH        = 40;
ARM_THICK        = 12;
CARRIAGE         = 35;     // mıknatıs taşıyıcı
MAGNET_D         = 18;     // neodyum mıknatıs çapı
TURNTABLE_D      = 130;    // lazy-susan tabla çapı
NEMA             = 42.3;   // NEMA17 gövde

/* [Görünüm] */
SHOW_GLASS       = true;
SHOW_SAND        = true;
EXPLODE          = 0;      // 0 = montajlı, >0 patlatılmış görünüm (mm)
$fn              = 120;

// ----------------------------------------------------------------------------
//  RENK/MALZEME yardımcıları (sadece önizleme için)
// ----------------------------------------------------------------------------
module body_color()  color([0.18,0.13,0.10]) children();   // koyu ceviz ahşap
module metal()       color([0.75,0.75,0.78]) children();
module glassc()      color([0.7,0.85,0.9,0.18]) children();
module sandc()       color([0.86,0.78,0.62]) children();
module ledc()        color([0.2,0.6,1.0,0.9]) children();

// ----------------------------------------------------------------------------
//  1) GÖVDE (silindirik kabin + alt taban)
// ----------------------------------------------------------------------------
module enclosure() {
    body_color() difference() {
        cylinder(d=TABLE_DIAMETER, h=TABLE_HEIGHT);
        // iç boşluk
        translate([0,0,WALL])
            cylinder(d=TABLE_DIAMETER-2*WALL, h=TABLE_HEIGHT);
        // üst açıklık (cam oturma kademesi)
        translate([0,0,TABLE_HEIGHT-GLASS_THICK-2])
            cylinder(d=TABLE_DIAMETER-2*8, h=GLASS_THICK+4);
    }
}

// ----------------------------------------------------------------------------
//  2) NEMA17 step motor (basit gövde)
// ----------------------------------------------------------------------------
module nema17(shaft=24) {
    metal() {
        cube([NEMA,NEMA,40], center=true);
        translate([0,0,20]) cylinder(d=22, h=2);
        translate([0,0,20]) cylinder(d=5, h=shaft);
    }
}

// ----------------------------------------------------------------------------
//  3) DÖNEN TABLA + KOL + TAŞIYICI (polar mekanizma)
// ----------------------------------------------------------------------------
module turntable() {
    metal() cylinder(d=TURNTABLE_D, h=8);
}

module arm() {
    // ρ ekseni: kol + üstünde lineer ray + taşıyıcı
    color([0.3,0.3,0.32]) difference() {
        hull() {
            cylinder(d=ARM_WIDTH, h=ARM_THICK);
            translate([ARM_LENGTH,0,0]) cylinder(d=ARM_WIDTH*0.6, h=ARM_THICK);
        }
        // hafifletme kanalı
        translate([ARM_WIDTH/2,0,ARM_THICK-3])
            cube([ARM_LENGTH, 8, 6], center=false);
    }
}

module carriage(rho=0.6) {
    // rho: 0..1 kol üzerindeki konum
    x = ARM_LENGTH * rho;
    translate([x,0,ARM_THICK]) {
        color([0.1,0.1,0.1]) cube([CARRIAGE,CARRIAGE,10], center=true);
        // neodyum mıknatıs
        color([0.6,0.6,0.65])
            translate([0,0,8]) cylinder(d=MAGNET_D, h=6);
    }
}

module mechanism(theta=25, rho=0.65) {
    translate([0,0,WALL+10]) {
        // θ tahrik motoru (sabit, tabanda)
        translate([TABLE_DIAMETER/2-50,0,-5]) nema17();
        // dönen tabla + kol
        rotate([0,0,theta]) {
            turntable();
            translate([0,0,8]) arm();
            // ρ motoru kol ucunda (kabloları slip ring'den)
            translate([0,0,8]) rotate([0,0,0])
                translate([-ARM_WIDTH/2,0,0]) scale(0.7) nema17(12);
            translate([0,0,8]) carriage(rho);
        }
    }
}

// ----------------------------------------------------------------------------
//  4) LED HALKA (kenar aydınlatma)
// ----------------------------------------------------------------------------
module led_ring() {
    ledc() translate([0,0,TABLE_HEIGHT-GLASS_THICK-LED_RING_H])
        difference() {
            cylinder(d=TABLE_DIAMETER-2*10, h=LED_RING_H);
            translate([0,0,-1]) cylinder(d=TABLE_DIAMETER-2*16, h=LED_RING_H+2);
        }
}

// ----------------------------------------------------------------------------
//  5) KUM + CAM (görsel katmanlar)
// ----------------------------------------------------------------------------
module sand() if (SHOW_SAND)
    sandc() translate([0,0,TABLE_HEIGHT-GLASS_THICK-SAND_DEPTH])
        cylinder(d=TABLE_DIAMETER-2*14, h=SAND_DEPTH);

module glass() if (SHOW_GLASS)
    glassc() translate([0,0,TABLE_HEIGHT-GLASS_THICK])
        cylinder(d=TABLE_DIAMETER-2*6, h=GLASS_THICK);

// ----------------------------------------------------------------------------
//  MONTAJ
// ----------------------------------------------------------------------------
module assembly() {
    enclosure();
    mechanism(theta=25, rho=0.65);
    translate([0,0,EXPLODE*1]) led_ring();
    translate([0,0,EXPLODE*2]) sand();
    translate([0,0,EXPLODE*3]) glass();
}

// ====== ÇIKTI SEÇİMİ ======
// Tüm montaj önizleme:
assembly();

// STL için tek parça istersen üsttekini yorum satırı yap ve birini aç:
// enclosure();
// arm();
// carriage();
// led_ring();

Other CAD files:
docs/uretim/dxf/ayak_plakasi.dxf
docs/uretim/dxf/kol.dxf
docs/uretim/dxf/sasi.dxf

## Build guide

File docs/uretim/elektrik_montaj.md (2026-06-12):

# Elektrik Montaj Talimatı (Electrical Work Instruction)

> ⚠️ **220 VAC** ile çalışılır. Mains bağlantılarını **yetkili** yapsın. Topraklama zorunlu.
> Kart **ESD**'ye duyarlı — topraklı bileklik kullanın. Tüm bağlantılar **güç KAPALI** yapılır.

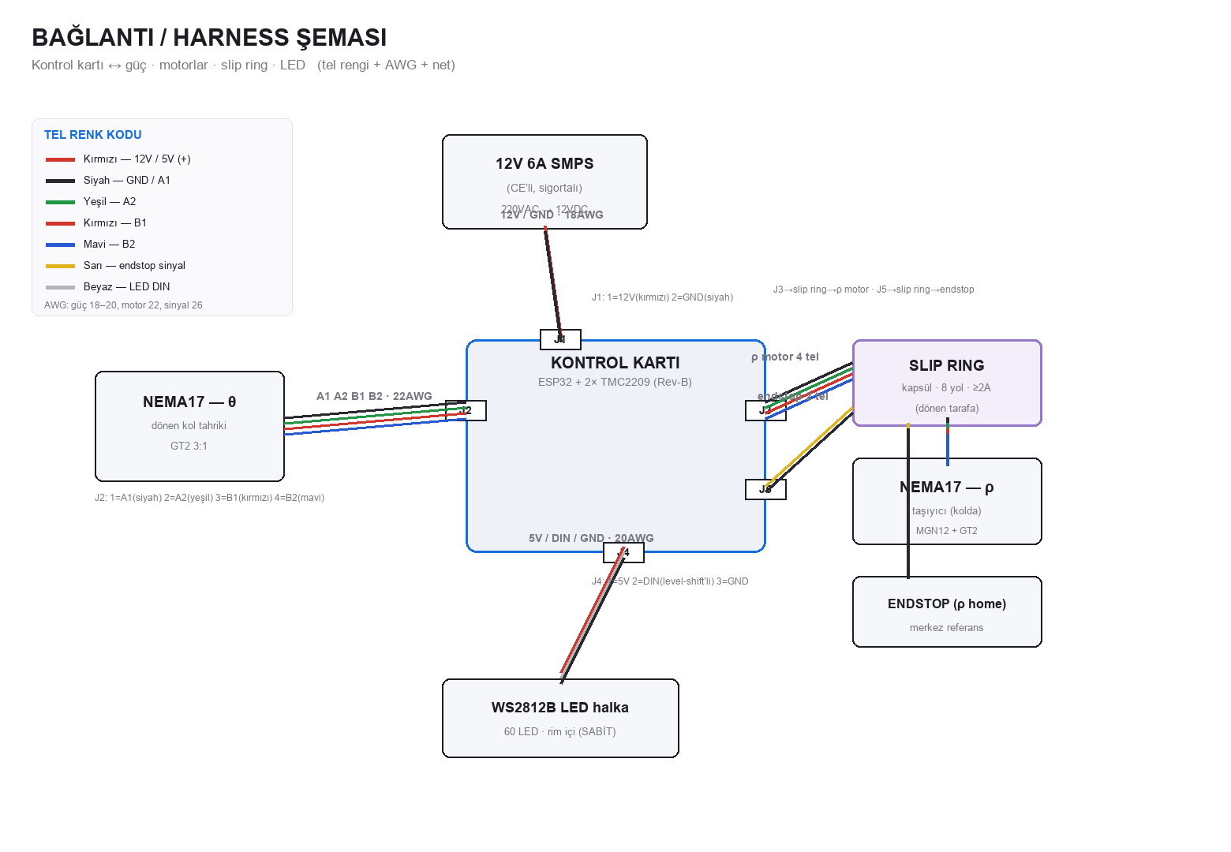
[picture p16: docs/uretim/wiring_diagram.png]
bağlantı şeması


Materyal/mekanik montaj **ayrı** sayfadadır: [`montaj.md`](montaj.md) (+ IKEA PDF: `MONTAJ_KILAVUZU.pdf`).

---

## 1) Konnektör pinout (kontrol kartı)
Kart üzeri konum (mm, kart orijinine göre) + tel:

| Konnektör | Konum | Pin → Net | Tel (renk · AWG) | Gider |
|---|---|---|---|---|
| **J1** güç | (6, 60) | 1=12V · 2=GND | kırmızı/siyah · 18 | 12V SMPS |
| **J2** θ motor | (6, 6) | 1=A1 2=A2 3=B1 4=B2 | siyah/yeşil/kırmızı/mavi · 22 | NEMA17 θ (gövde içi) |
| **J3** ρ motor | (72, 6) | 1=A1 2=A2 3=B1 4=B2 | siyah/yeşil/kırmızı/mavi · 22 | **slip ring → ρ motor** |
| **J4** LED | (66, 60) | 1=5V 2=DIN 3=GND | kırmızı/beyaz/siyah · 20 | WS2812B halka (level-shifter’lı) |
| **J5** endstop | (40, 6) | 1=3V3 2=SİNYAL 3=GND | —/sarı/siyah · 26 | **slip ring → endstop** |

> NEMA17 faz eşlemesi modele göre değişir — **bobin çiftlerini ohmmetre ile doğrula**
> (aynı bobinin iki ucu ~2–4 Ω; çiftler arası açık devre). Yanlış çift → motor titrer/dönmez.

## 2) Slip ring tel haritası (8 yollu kapsül)
ρ motoru kolla döndüğü için kablosu slip ring’ten geçer (stator=baz, rotor=kol):

| Slip ring teli | Sinyal | Stator ucu | Rotor ucu |
|---|---|---|---|
| W1 | ρ A1 | J3-1 | ρ motor A1 |
| W2 | ρ A2 | J3-2 | ρ motor A2 |
| W3 | ρ B1 | J3-3 | ρ motor B1 |
| W4 | ρ B2 | J3-4 | ρ motor B2 |
| W5 | endstop sinyal | J5-2 | endstop sinyal |
| W6 | GND (lojik) | J5-3 | endstop GND |
| W7,W8 | yedek | — | — |

> Sürücüler **bazda** (PCB’de) — slip ring **motor akımı** (~0.8A) taşır; ≥2A/yol şart.
> LED **sabit** rim’de → slip ring’e **girmez**.

## 3) Montaj sırası (elektrik)
1. **SMPS girişi (mains):** 220VAC L/N + **topraklama (PE)** → SMPS; giriş hattına **sigorta**.
   Mains kablolarını **ferrül + yalıtım**; gövdeye gerilim aktarımı yok.
2. **12V → J1:** SMPS 12V(+)/GND → J1 (kırmızı/siyah 18AWG). Polariteyi doğrula (karttaki ters-polarite
   koruması yedektir, yine de doğru bağla).
3. **θ motor → J2:** bobin çiftlerini ohmmetre ile bul, A1A2/B1B2 sırasıyla bağla.
4. **Slip ring:** stator W1–W6 → J3 (4) + J5 (2); rotor W1–W6 → ρ motor (4) + endstop (2).
   Slip ring’i dönme ekseninde merkeze sabitle; rotor kablosunu kola, stator kablosunu baza.
5. **LED → J4:** 5V/DIN/GND. DIN karttaki **level-shifter** çıkışından; ilk LED’e gider.
   LED gücü ayrı 5V hattıyla beslenebilir (60 LED tam beyaz ~3.6A).
6. **Kablo yönetimi:** spiral/kanal, **gerilim azaltıcı (strain relief)**, dönen kol kablosuna
   **bükülme payı** (slip ring’e kadar serbest döner). Tüm kabloları **etiketle**.

## 4) İlk güç verme (motor BAĞLAMADAN)
Önce QA listesi §2: 12V/5V/3V3 ölçümü + ESP32 boot. **Sonra** motorları bağla.
→ Tam prosedür: [`QA_kontrol_listesi.md`](QA_kontrol_listesi.md)

## 5) Güvenlik / CE
- Mains izolasyonu, **PE topraklama** sürekliliği (<0.1Ω), çift yalıtım veya topraklı gövde.
- Sigorta (giriş), SMPS **CE/EMC**’li.
- LED/motor düşük gerilim (SELV) tarafı mains’ten ayrık.
- Üretimde **hi-pot / topraklama süreklilik** testi (QA §1) önerilir.

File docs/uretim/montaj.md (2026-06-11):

# Montaj Sheet — Kinetik Kum Masası (Ø600, ayaklı sehpa)

Hesaplanmış geometri, açılar, delik konumları, bağlantı çizelgesi ve **mıknatıslı modüler** yapı.
Çizim: **`montaj_sheet.svg`** (ön + üst görünüş, ölçülü). Geometri üreteci: `montaj_hesap.py`.

> Yapı felsefesi: **birbirine geçen + vidalanan** ana gövde; **güçlü mıknatıslarla** ayrılıp
> birleşen **üst modül** (cam + kum yatağı) → bakım için mekanizmaya kolay erişim.

---

## 1) Hesaplanmış ana ölçüler (mm)
| Büyüklük | Değer | Not |
|---|---|---|
| Drum dış çap | **Ø600** | et 18 (ceviz kaplama) |
| Kum havuzu | **Ø540 × derinlik 50** | cidardan 24 içerde |
| Kum yatağı | **Ø516** | |
| Temperli cam | **Ø552 × 6** | rabbet'e oturur |
| Ayak | **4 × 320 mm, 8° splay** | masif ceviz koni |
| Ayak bağlantı dairesi (PCD) | **Ø420** | açılar 45° / 135° / 225° / 315° |
| Ayak ucu temas dairesi | **Ø509** | dışa kaçış 44.5 mm/ayak |
| Ayak dikey izdüşümü | **316.9 mm** | = 320·cos8° |
| **Toplam masa yüksekliği** | **≈ 467 mm** | drum 150 + ayak 316.9 |

## 2) Ayak montajı (açı kritik)
- 4 ayak, **Ø420 PCD** üzerinde 90°'de, her biri **radyal yönde 8° dışa** eğimli.
- Drum alt tablasına **8° eğimli ayak bağlantı plakası** (hazır mobilya plakası ya da CNC freze cep)
  ile vidalanır. Plaka deliği: **4× M5**, 30×30 desen.
- Ahşaba **M6 gömme dişli (threaded insert)** + **M6×30 paslanmaz civata** (plaka üzerinden).
- Ayak ucu yere temas çapı Ø509 → devrilme stabilitesi yüksek (taban/yükseklik ≈ 1.09).

## 3) Mıknatıslı üst modül (bakım erişimi)
Üst modül = **temperli cam + kum yatağı çerçevesi** tek parça; drum rim'ine **mıknatısla** oturur, elle kaldırılır.
| Parametre | Değer |
|---|---|
| Tutucu mıknatıs | **8 × N52 Ø20×3 mm** @ **Ø572 PCD** (45°) |
| Karşı eleman | rim cebinde mıknatıs / modül çerçevesinde **Ø22 × 1.5 DKP saç** karşı plaka |
| Üst modül ağırlığı | **≈ 4.2 kg** (cam 3.6 + çerçeve 0.6) |
| Toplam tutma kuvveti | **≈ 21.6 kgf** |
| **Güvenlik katsayısı** | **≈ 5.2×** (kaldırmaya karşı; yanal kayma için merkezleme pimleri) |
- 2 adet **Ø6 merkezleme pimi** (çelik) modülün yanal kaymasını engeller; mıknatıslar sadece düşey tutar.

## 4) Mekanizma (drum içi, kum yatağının altında)
| Bileşen | Bağlantı / delik | Eleman |
|---|---|---|
| **Şasi plakası** (Al 4mm Ø520) | drum alt tablasına 4× **M4 standoff** @ Ø500 PCD | M4×... + standoff |
| **θ motoru** (NEMA17, merkez) | **31×31 mm kare M3** delik deseni, merkez Ø22 boşluk | 4× M3×8 |
| **Turntable** (lazy-susan Ø150) | şasiye 4× M4; üstüne dönen kol | 4× M4×10 |
| **Dönen kol** (Al 5mm) | turntable'a 4× M3; ucunda ρ motoru + MGN12 ray | M3 |
| **ρ motoru** (NEMA17, kol ucu) | 31×31 M3; kabloları **slip ring** üzerinden | 4× M3×8 |
| **Taşıyıcı + mıknatıs** | MGN12 araba üzerine; N52 Ø20×10 cebe | 2× M3 |
| **Slip ring** | şasi merkezine bilezik; dönen tarafa kelepçe | M3 |
| **Kontrol kartı (PCB)** | şasiye 4× M3 standoff, yan duvara klemensler | 4× M3×6 |
| **LED halka (WS2812B)** | rim iç kenarına yapışkan + 330Ω + 1000µF | — |

## 5) Bağlantı (vida) çizelgesi
| Yer | Eleman | Adet |
|---|---|---|
| Ayak → drum (eğimli plaka) | M6×30 civata + M6 insert | 16 (4/ayak) |
| Şasi → drum tablası | M4×16 + standoff | 4 |
| θ / ρ motor → şasi/kol | M3×8 | 8 |
| Turntable / kol / taşıyıcı | M3–M4 | ~14 |
| PCB standoff | M3×6 | 4 |
| Rim → gövde | M4×16 (gizli) veya ahşap tutkalı + biskü | 8 |
| Üst modül merkezleme | Ø6 çelik pim | 2 |

## 6) Toleranslar & notlar
- Cam–havuz rabbet boşluğu: **+0.5 mm** çevresel (termal/montaj).
- Mıknatıs–çelik hava aralığı (cam altı, kum üstü): bilye sürücü için **toplam ≤ 12 mm**
  (cam 6 + kum 5) → N52 Ø20×10 ~7g bilyeyi rahat sürükler.
- MGN12 ray paralelliği: kol ekseninde **±0.2 mm**.
- Tüm ahşap kesimler CNC; ayak açısı plakadan gelir (elde açı verilmez).
- Topraklama: alüminyum şasi → güç toprağına; LED 5V hattı ayrı buck.

## 7) Montaj sırası
1. Ahşap gövde + rim + kaplama/cila (atölye çıkışı).
2. Ayakları 8° plakalarla drum altına civatala (PCD Ø420).
3. Şasi plakasını drum tablasına standoff'la monte et; θ motoru + turntable + kol + ρ motor + ray + taşıyıcı/mıknatıs + slip ring.
4. Kontrol kartı + kablolama + LED halka + güç.
5. Firmware (Dune Weaver) yükle, **kalibrasyon** (`firmware/README.md`): θ tam tur, ρ menzil, bilye sürükleme.
6. Kum yatağı + cam → mıknatıslı **üst modül** olarak oturt (merkezleme pimleri).
7. Kum doldur, desen (`firmware/patterns/` → Atatürk imzası / spiral) yükle, test.

---
**İlgili dosyalar:** `BOM_uretim.md` (malzeme+fiyat), `montaj_sheet.svg` (çizim),
`montaj_hesap.py` (parametrik geometri — ölçü değişince yeniden üretir),
`../../hardware/pcb/` (kontrol kartı), `../../hardware/sand_table.scad` (3D model).

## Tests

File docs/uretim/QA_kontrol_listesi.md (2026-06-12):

# QA / Bring-up & Fonksiyonel Test Fişi (FCT)

**Ünite seri no:** ____________  **Tarih:** __________  **Operatör:** ____________
**Rev:** PCB Rev-B · FluidNC ____  **Sonuç:** ☐ GEÇTİ  ☐ KALDI  **İmza:** __________

> Sırayı atlamayın. Her adımda **ölç → yaz → işaretle**. Bir KALDI varsa durun, kök neden bulun.

---

## 1) Gelen muayene + emniyet (güç YOK)
| # | Kontrol | Beklenen | Ölçüm | ✓/✗ |
|---|---|---|---|---|
|1.1| Görsel: lehim/komponent/yön (U2,Q1,D1 polarite) | kusursuz | — | ☐ |
|1.2| 12V–GND kısa devre (ohm) | yüksek (>1kΩ) | _____ Ω | ☐ |
|1.3| 5V–GND kısa devre | yüksek | _____ Ω | ☐ |
|1.4| 3V3–GND kısa devre | yüksek | _____ Ω | ☐ |
|1.5| PE topraklama sürekliliği (gövde) | <0.1 Ω | _____ Ω | ☐ |

## 2) Güç verme (motor BAĞLI DEĞİL)
| # | Test noktası | Beklenen | Ölçüm | ✓/✗ |
|---|---|---|---|---|
|2.1| J1 giriş | 11.4–12.6 V | _____ V | ☐ |
|2.2| 5V rayı (buck çıkışı) | 4.90–5.10 V | _____ V | ☐ |
|2.3| 3V3 rayı (ESP32) | 3.25–3.35 V | _____ V | ☐ |
|2.4| Boşta akım (12V) | < 0.30 A | _____ A | ☐ |
|2.5| ESP32/sürücü ısınma (1 dk) | el ile ılık-altı | — | ☐ |
|2.6| Ters polarite testi (kısa, bilerek ters) | hasar yok (Q1 keser) | — | ☐ |

## 3) Haberleşme / firmware
| # | Kontrol | Beklenen | ✓/✗ |
|---|---|---|---|
|3.1| FluidNC açılıyor (seri/WebUI) | versiyon banner | ☐ |
|3.2| `$Stepper` / config okunuyor | hata yok | ☐ |
|3.3| (UART modu) iki sürücü ayrı adres yanıtı | addr 0 ve 1 | ☐ |

## 4) Hareket (motorlar bağlı, mekanizma serbest)
| # | Test | Beklenen | Ölçüm | ✓/✗ |
|---|---|---|---|---|
|4.1| TMC akım ayarı | 0.6–0.9 A/faz | _____ A | ☐ |
|4.2| θ tam tur (A 360°) | kayma/atlama yok | — | ☐ |
|4.3| ρ ileri/geri (X 0→250→0) | düzgün, ses az | — | ☐ |
|4.4| ρ homing (endstop) | tetikler, durur | — | ☐ |
|4.5| θ yön / ρ yön doğru | desenle uyumlu | — | ☐ |

## 5) LED
| # | Test | Beklenen | ✓/✗ |
|---|---|---|---|
|5.1| Tüm LED yanıyor (test deseni) | eksik/yanlış renk yok | ☐ |
|5.2| Level-shifter (DIN 5V) kararlı | titreme yok | ☐ |

## 6) Fonksiyonel (sistem, kum+bilye)
| # | Test | Beklenen | ✓/✗ |
|---|---|---|---|
|6.1| Mıknatıs bilyeyi sürüklüyor | kaçırma yok (orta hız) | ☐ |
|6.2| Tam desen (Atatürk imza / spiral) | temiz oluk, merkezde | ☐ |
|6.3| Kuplaj max hız (kalibrasyon) | _____ mm/s’de stabil | ☐ |

## 7) Dayanıklılık
| # | Test | Beklenen | ✓/✗ |
|---|---|---|---|
|7.1| 24h burn-in (sürekli desen) | hata/ısınma/atlama yok | ☐ |
|7.2| Gürültü seviyesi | kabul (≤ ____ dBA) | ☐ |

## 8) Final QA
| # | Kontrol | ✓/✗ |
|---|---|---|
|8.1| Cam/üst modül mıknatıs oturuyor, boşluk yok | ☐ |
|8.2| Ayak stabilite (sallanma yok) | ☐ |
|8.3| Etiket / seri no / kullanım kılavuzu | ☐ |
|8.4| Ambalaj uygun | ☐ |

**Notlar:** ____________________________________________________________________

> Test noktaları: 12V=J1, 5V=C1/BK1 çıkışı, 3V3=ESP32 3V3 pini, akım=seri ampermetre.
> Akış: `elektrik_montaj.md` → bu fiş → `URETIM_DOSYASI.md §5`.

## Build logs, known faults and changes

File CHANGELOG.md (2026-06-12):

# Değişiklik Geçmişi — DEVRAN

[Keep a Changelog](https://keepachangelog.com/tr/) biçimine yakın. Tarihler yaklaşık.

## [Devam ediyor]
- Fusion'da COTS (MGN12, lazy-susan, slip ring) fit doğrulama
- PCB Rev-B fiziksel prototip + bring-up testi
- Gerçek prototip fotoğraf/video (satış görseli)
- CE / elektrik güvenlik belgelendirme

## Marka & sunum
- **Marka kimliği:** DEVRAN adı + polar-spiral logo/favicon, tüm site + dokümanlara uygulandı
- **Profesyonel datasheet** (D60 spec sheet) + **iş/yatırım pitch** PDF
- **Modern web sitesi** baştan: premium dark tema, her doküman ayrı sayfa (MD→HTML), hub
- **Teknik çizim montaj** PDF (2D ölçülü, antet bloğu) — 3D render kılavuzuna ek
- Profesyonel README + bu CHANGELOG

## Üretim paketi
- **PCB Rev-B:** UART adresleme, WS2812 level-shifter, giriş koruması, bulk cap, EN pull-up
  → yeniden route (196 iz, 0 short); **JLCPCB paketi** (Gerber+BOM+CPL)
- **Mekanizma tasarımı:** θ/ρ kinematik + kesit + çözünürlük hesabı + slip ring
- **Mekanik DXF + STEP** (şasi/ayak/kol) · **IKEA tarzı montaj kılavuzu** (PDF)
- **Elektrik:** harness şeması + pinout + slip ring haritası + **QA/FCT test fişi**
- **Üretim gerçekleme dosyası** (NPI/EVT-DVT-PVT, test planı, COGS, risk)
- **BOM + maliyet** (TR tedarik) + hedef MSRP · **FluidNC config** (PCB pinmap ile eşleşir)
- **Gerçek oluk** (heightmap displacement): bilye kumu gerçekten oyar

## Görsel & simülasyon
- **AgX** tone mapping + sığ DOF + 512 spp fotogerçekçi render'lar
- **Reklam videosu:** ilerleyen ışıklı oluk → Atatürk imzası net çiziliyor
- **İnteraktif 3D sim** (Three.js): desen seç → çiz, parçalara ayır; ayna/cam/kontrol düzeltmeleri
- Atatürk imzası `.thr` deseni (skeletonize + NN path)

## Temel
- KiCad PCB (ESP32 + 2× TMC2209 + WS2812 + güç), Freerouting tam routing
- Blender prosedürel sahne (`scene.py`), `.thr` desen üreteçleri
- Proje kurulumu, GitHub repo

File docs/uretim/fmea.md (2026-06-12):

# FMEA + Gereksinim & Test İzlenebilirliği

Hata Modu ve Etkileri Analizi (FMEA) + ürün gereksinim spesifikasyonu (PRD) ve
gereksinim→test izleme matrisi. Global donanım geliştirmede standart mühendislik rigoru.

---

## 1) Ürün gereksinimleri (PRD — özet)
| ID | Gereksinim | Doğrulama (test) |
|---|---|---|
| **R1** | Desen çözünürlüğü ≥ sub-mm (kenar) | T-MECH-1 |
| **R2** | θ sürekli dönme, ρ 0–250 mm, homing | T-MOT-2/3 |
| **R3** | Bilye kaçırmadan sürüklenir (≤ hedef hız) | T-FUNC-1 |
| **R4** | Gürültü ≤ ~35 dBA (oturma odası) | T-NOISE |
| **R5** | 5V/12V raylar tolerans içinde, LED kararlı | T-PWR-1/2, T-LED |
| **R6** | 7/24 çalışmada atlama/ısınma yok (ömür) | T-BURN (≥24h, hedef ≥1000h) |
| **R7** | Üst modül emniyetli tutma (SF ≥ 3) | hesap: SF 5.2× ✓ |
| **R8** | Ağ güvenliği: yetkisiz erişim yok | T-SEC |
| **R9** | Devrilme stabilitesi (mobilya std) | T-STAB |
| **R10** | EMC/emniyet uyumlu | [sertifikasyon](sertifikasyon.md) |

## 2) FMEA (S=şiddet, O=olasılık, D=tespit; RPN=S×O×D, 1–10)
| # | Öğe / fonksiyon | Hata modu | Etki | S | O | D | RPN | Önlem |
|---|---|---|---|--:|--:|--:|--:|---|
|F1| 12V giriş | ters polarite | kart hasarı | 7 | 3 | 2 | 42 | P-FET + sigorta (Rev-B) ✓ |
|F2| WS2812 data | 3.3V seviye yetersiz | LED titrer/yanmaz | 4 | 6 | 3 | 72 | level-shifter (Rev-B) ✓ |
|F3| TMC2209 UART | adres çakışması | sürücü ayarlanamaz | 6 | 5 | 3 | 90 | ayrı MS adres (Rev-B) ✓ |
|F4| Slip ring | kontak gürültü/aşınma | ρ motor kesilir | 7 | 4 | 4 | 112 | ≥2A kaliteli kapsül, akım düşük; periyodik bakım |
|F5| Manyetik kuplaj | hızda bilye kaçar | desen bozulur | 5 | 5 | 2 | 50 | hız limiti + aralık ≤10mm + mıknatıs büyüt |
|F6| θ yatak | boşluk/salınım | desen kayması | 6 | 4 | 5 | 120 | kaliteli ince-kesit rulman + kayış gerginliği |
|F7| ρ kayış | atlama (skip) | konum kayması | 6 | 4 | 5 | 120 | doğru gerginlik + akım; homing referansı |
|F8| Motor/sürücü | aşırı ısınma | kapanma/ömür | 6 | 3 | 4 | 72 | akım 0.6–0.9A, havalandırma, burn-in |
|F9| Temperli cam | kırılma | yaralanma | 9 | 2 | 2 | 36 | temperli + rodaj + yük testi |
|F10| Üst mıknatıs modül | parmak sıkışması | yaralanma | 7 | 3 | 3 | 63 | ikaz + kaldırma tasarımı |
|F11| Firmware | güç kesintisi sonrası kayıp | yeniden home gerek | 4 | 5 | 3 | 60 | açılışta auto-home + durum kaydı |
|F12| Ağ | yetkisiz erişim | kontrol ele geçer | 7 | 3 | 5 | 105 | AP şifre, yerel ağ, OTA imzalama, port kısıtla |
|F13| Wi-Fi/EMC | parazit/uyumsuzluk | sertifika kalır | 6 | 4 | 4 | 96 | ön-sertifikalı modül + EMC pre-scan |

**En yüksek RPN'ler (öncelik):** F6/F7 (mekanik boşluk/atlama, 120), F4 (slip ring, 112), F12 (güvenlik, 105),
F13 (EMC, 96), F3 (90). Bunlar **prototip/bring-up testinde** özellikle doğrulanmalı.

## 3) Gereksinim → Test izleme matrisi
| Gereksinim | Test (QA fişi / plan) | Durum |
|---|---|---|
| R1 | T-MECH-1 (çözünürlük) | hesap ✓ · donanım ⏳ |
| R2 | [QA](QA_kontrol_listesi.md) §4.2–4.4 | ⏳ prototip |
| R3 | QA §6.1 | ⏳ |
| R4 | T-NOISE (dBA ölçüm) | ⏳ |
| R5 | QA §2.1–2.3, §5 | ⏳ |
| R6 | QA §7.1 burn-in | ⏳ |
| R7 | mıknatıs hesabı (SF 5.2×) | ✓ |
| R8 | T-SEC (penetrasyon) | ⏳ |
| R9 | T-STAB (devrilme) | ⏳ |
| R10 | [sertifikasyon](sertifikasyon.md) | ⏳ |

> "⏳" kalemler **fiziksel prototip** gerektirir — yazılımda kapatılamaz. FMEA, bring-up ve
> DVT test planının girdisidir ([üretim dosyası §5](URETIM_DOSYASI.md)).

## 4) Süreç (global pro)
Tasarım → **FMEA** (bu) → risk azaltma → prototip → **bring-up + DVT testleri** (gereksinime bağlı) →
ECO ile düzeltme → PVT → üretim. Her revizyonda FMEA güncellenir ([CHANGELOG](../../CHANGELOG.md)).

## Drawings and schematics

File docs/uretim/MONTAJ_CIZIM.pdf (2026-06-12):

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

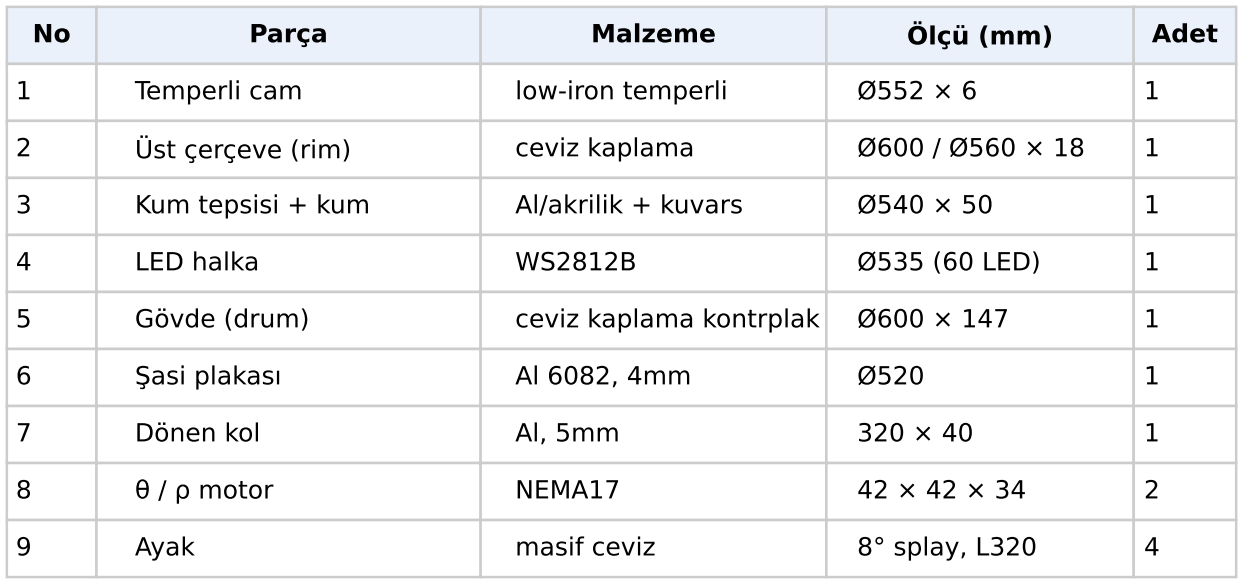
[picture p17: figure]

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

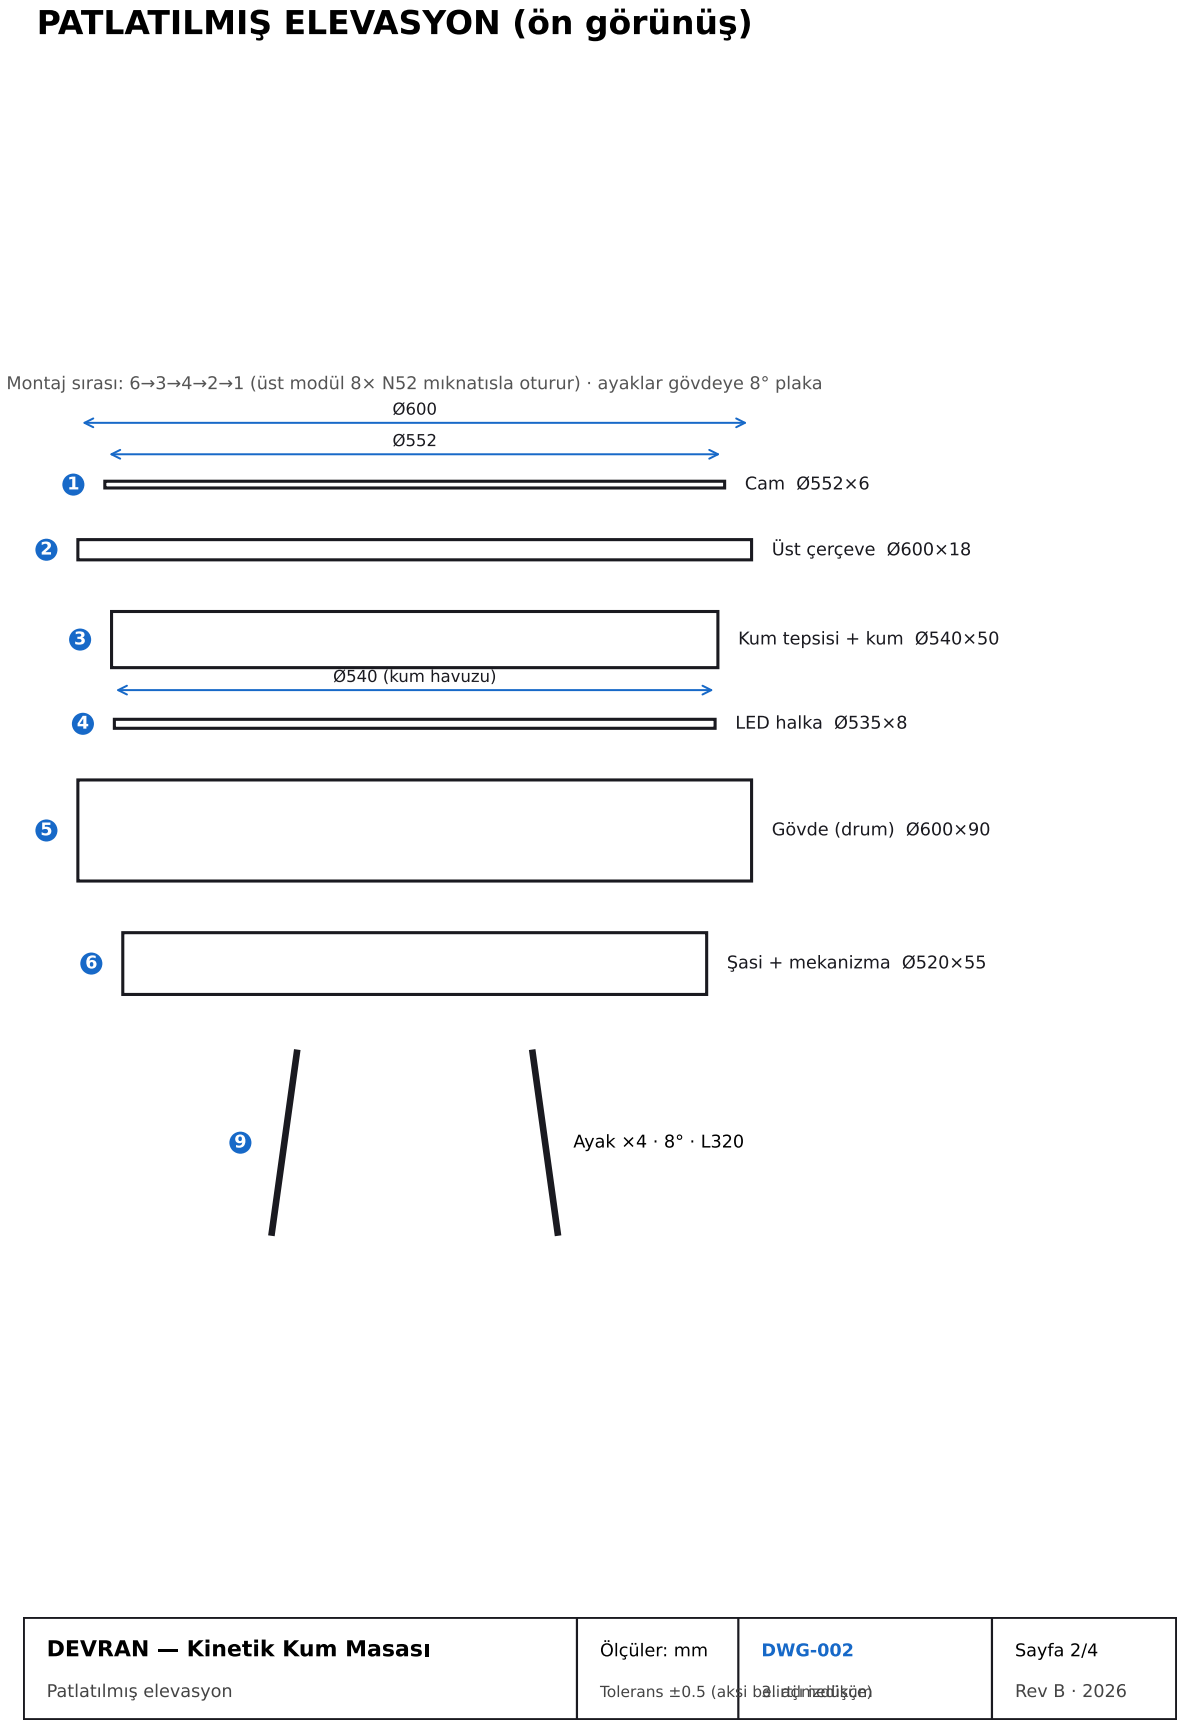
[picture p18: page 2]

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

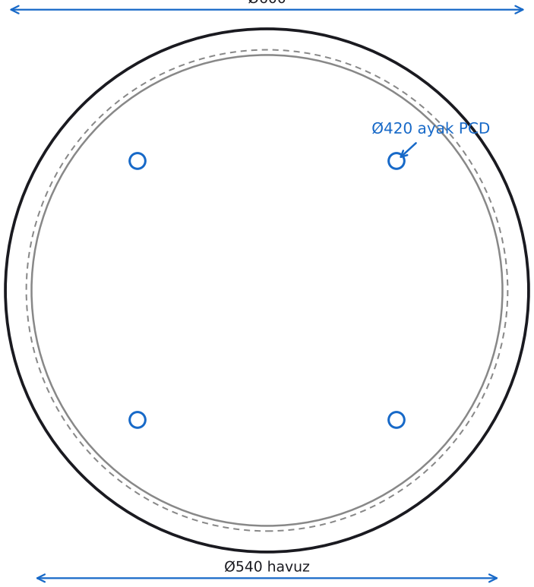
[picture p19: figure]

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

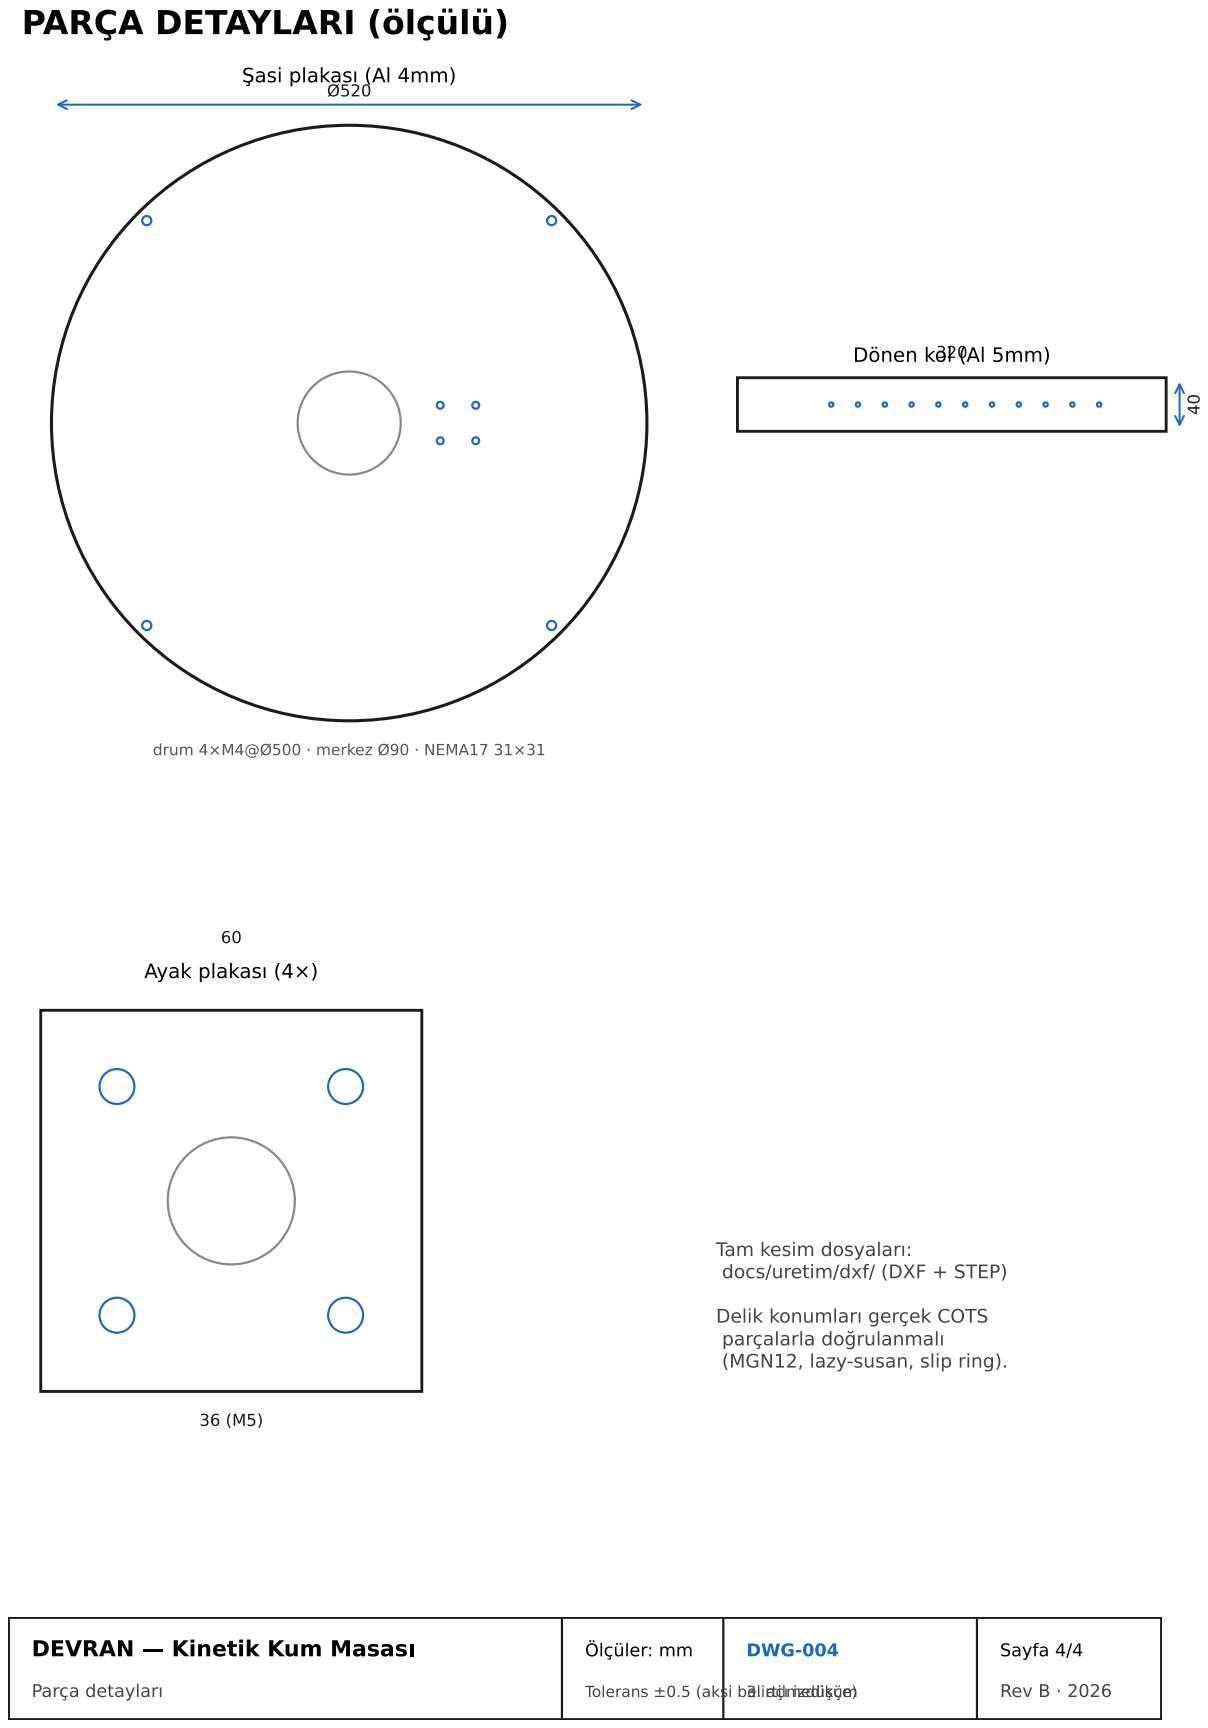
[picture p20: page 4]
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

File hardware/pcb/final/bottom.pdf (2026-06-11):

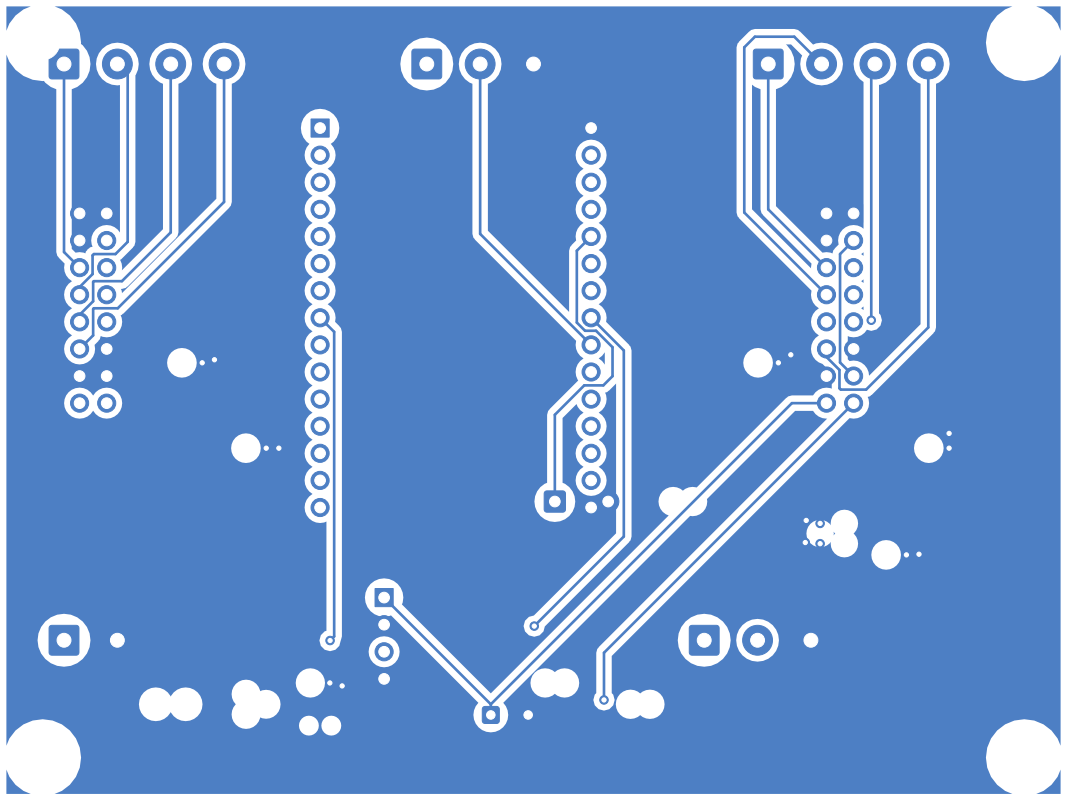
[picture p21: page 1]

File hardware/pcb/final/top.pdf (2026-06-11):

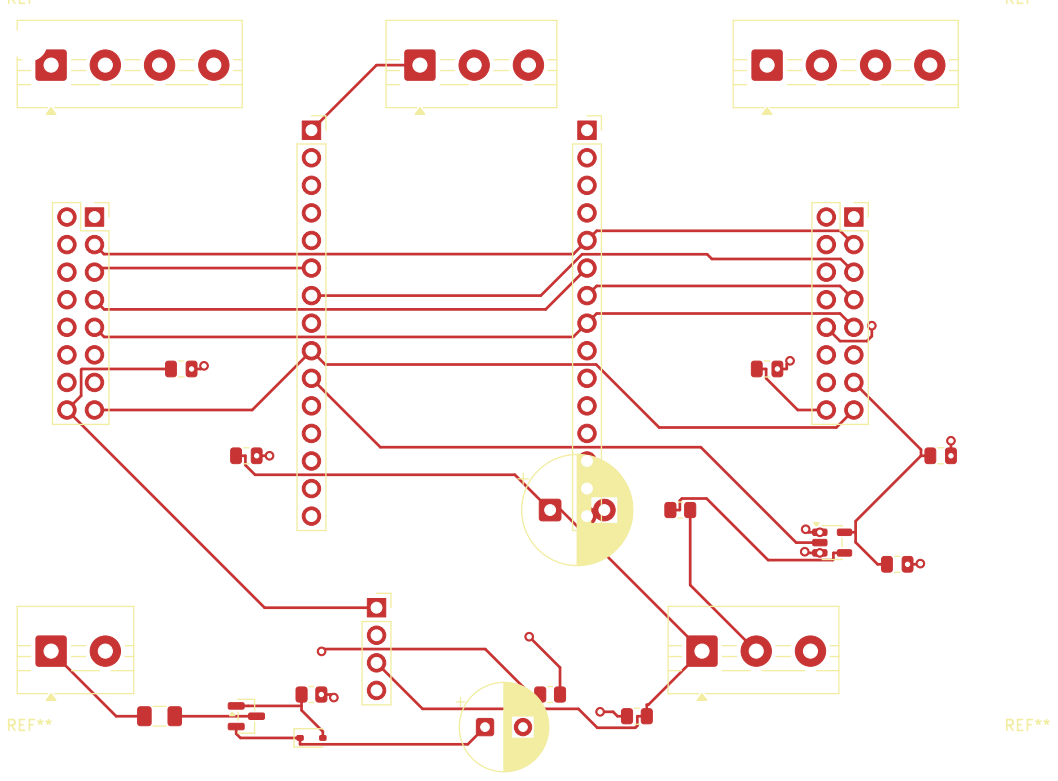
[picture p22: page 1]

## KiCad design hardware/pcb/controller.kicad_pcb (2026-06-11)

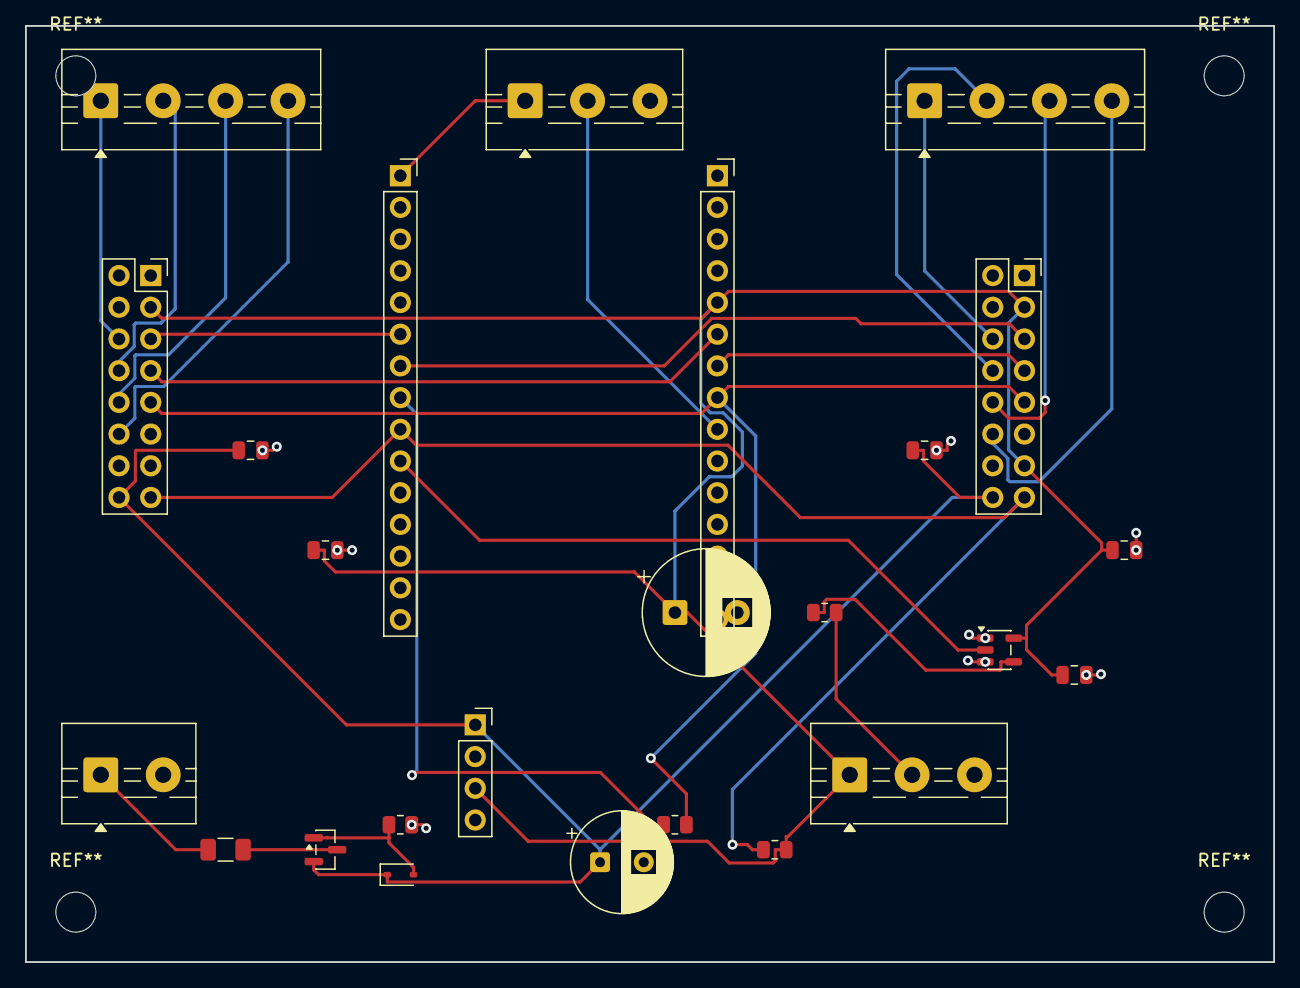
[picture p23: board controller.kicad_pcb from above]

Board: 2 copper layers, 100.0 x 75.0 mm, 25 parts (0 on the bottom side), 26 nets.

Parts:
A1, A2: PinSocket_2x08_P2.54mm_Vertical
BK1: PinSocket_1x04_P2.54mm_Vertical
C1: CP_Radial_D10.0mm_P5.00mm
C2, C3, C5, C7, C8: C_0805_2012Metric
C6: CP_Radial_D8.0mm_P3.50mm
D1: D_SOD-323
F1: Fuse_1206_3216Metric
J1: TerminalBlock_MaiXu_MX126-5.0-02P_1x02_P5.00mm
J2, J3: TerminalBlock_MaiXu_MX126-5.0-04P_1x04_P5.00mm
J4, J5: TerminalBlock_MaiXu_MX126-5.0-03P_1x03_P5.00mm
Q1: SOT-23
R1, R2, R3, R4: R_0805_2012Metric
U1L, U1R: PinSocket_1x15_P2.54mm_Vertical
U2: SOT-23-5

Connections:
N_3V3: J5.1, U1L.1
N_5V: A1.3, A2.3, A2.13, BK1.3, C1.1, C2.1, C3.1, C5.1, J4.1, R3.2, U1R.5, U2.5
N_12V: A1.16, A2.16, BK1.1, C6.1, C7.1, C8.1, D1.1, Q1.2
N_12VF: F1.2, Q1.3
N_12VIN: F1.1, J1.1
N_EN: A1.15, A2.15, R3.1, U1L.9
N_ENDSTOP: J5.2, U1R.9
N_GND: A1.1, A1.2, A1.4, A1.11, A1.13, A1.14, A2.1, A2.2, A2.4, A2.11, A2.14, BK1.2, BK1.4, C1.2, C2.2, C3.2, C5.2, C6.2, C7.2, C8.2, J1.2, J4.3, J5.3, R2.2, U1R.1, U1R.15, U2.1, U2.3
N_LEDDIN: J4.2, R1.2
N_LEDDIN5: R1.1, U2.4
N_LEDG: U1L.10, U2.2
N_PDN: A1.9, A2.9, R4.2, U1R.8
N_PGATE: D1.2, Q1.1, R2.1
N_RHDIR: A2.5, U1L.7
N_RHSTEP: A2.7, U1R.7
N_THDIR: A1.5, U1L.6
N_THSTEP: A1.7, U1R.6
N_UART_TX: R4.1, U1L.8
RHM_A1: A2.6, J3.1
RHM_A2: A2.8, J3.2
RHM_B1: A2.10, J3.3
RHM_B2: A2.12, J3.4
THM_A1: A1.6, J2.1
THM_A2: A1.8, J2.2
THM_B1: A1.10, J2.3
THM_B2: A1.12, J2.4

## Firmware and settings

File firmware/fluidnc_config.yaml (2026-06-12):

# ============================================================================
#  FluidNC config — Kinetik Kum Masasi (polar / theta-rho)
#  ESP32 + 2x TMC2209. Pinler kontrol kartiyla (hardware/pcb) ESLESIR.
#  DURUM: cihaza yuklenip DOGRULANMADI. Ilk EVT'de STANDALONE mod (UART yok)
#  -> daha az ariza noktasi (bkz. docs/uretim/PCB_inceleme.md).
#  steps_per_mm degerleri TAHMINI -> donanimda KALIBRE edilecek.
# ============================================================================
name: "Kinetik Kum Masasi (polar)"
board: "ESP32 + 2x TMC2209 (controller.kicad_pcb)"

stepping:
  engine: RMT
  idle_ms: 250
  pulse_us: 4
  dir_delay_us: 1
  disable_delay_us: 0

# EN (active-low) her iki surucude ortak  (PCB: GPIO25)
axes:
  shared_stepper_disable_pin: gpio.25:low

  # ---- X = RHO (kol uzerinde kayan tasiyici, lineer) ----
  x:
    steps_per_mm: 80.0            # GT2 20T(40mm/dev) x 3200 step/dev / 40 = 80  (KALIBRE)
    max_rate_mm_per_min: 4000
    acceleration_mm_per_sec2: 300
    max_travel_mm: 250            # rho strok 0..R_max (mekanizma_tasarim.md); KALIBRE
    homing:
      cycle: 1
      positive_direction: false
      mpos_mm: 0
      feed_mm_per_min: 300
      seek_mm_per_min: 1000
      pulloff_mm: 2
    motor0:
      limit_neg_pin: gpio.22:low:pu   # rho home (endstop, PCB J5)
      standard_stepper:
        step_pin: gpio.21
        direction_pin: gpio.5         # not: GPIO5 strapping -> bkz inceleme

  # ---- A = THETA (donen kol, surekli donme) ----
  a:
    steps_per_mm: 26.667         # 3:1 reduksiyon (GT2 20T->60T): 3200x3/360 = 26.667 step/derece (KALIBRE)
    max_rate_mm_per_min: 9000
    acceleration_mm_per_sec2: 400
    max_travel_mm: 1000000       # surekli donme
    motor0:
      standard_stepper:
        step_pin: gpio.19
        direction_pin: gpio.18

# ---------------------------------------------------------------------------
# UART surumu (DVT - runtime akim/mikroadim): yukaridaki standard_stepper'lari
# tmc_2209 ile degistir + her surucuye AYRI adres (PCB_inceleme #1) ver:
#   uart1: {txd_pin: gpio.17, rxd_pin: gpio.16, baud: 115200, mode: 8N1}
#   x.motor0.tmc_2209: {uart_num: 1, addr: 0, r_sense_ohms: 0.11, run_amps: 0.8, microsteps: 16}
#   a.motor0.tmc_2209: {uart_num: 1, addr: 1, run_amps: 0.8, microsteps: 16}
# ---------------------------------------------------------------------------

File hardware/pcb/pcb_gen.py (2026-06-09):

#!/usr/bin/env python3
# ============================================================================
#  Kinetik Kum Masasi - Kontrol Karti uretici (gerbonara, saf Python)
#  Cikti: tam Gerber seti + Excellon drill + katman SVG render'lari + netlist
#  Calistir:  python3 pcb_gen.py
#  KiCad GEREKTIRMEZ. Uretilen Gerber'lar JLCPCB/PCBWay'e dogrudan yuklenebilir.
# ============================================================================
import os, math
from gerbonara.rs274x import GerberFile
from gerbonara.excellon import ExcellonFile, ExcellonTool
from gerbonara import graphic_objects as go, apertures as ap
from gerbonara.utils import MM
from gerbonara import LayerStack

OUT = os.path.dirname(os.path.abspath(__file__))
GERB = os.path.join(OUT, "gerbers"); os.makedirs(GERB, exist_ok=True)
PLOT = os.path.join(OUT, "plots");   os.makedirs(PLOT, exist_ok=True)

# ---- kart parametreleri (mm) ----
BW, BH = 100.0, 75.0          # kart olculeri
TRACE_SIG, TRACE_PWR = 0.3, 0.6
VIA_CU, VIA_DR = 0.8, 0.4
PAD_CU, PAD_DR = 1.7, 1.0     # standart THT pin
TERM_CU, TERM_DR = 2.4, 1.3   # vidali klemens (5.08 pitch)
MASK_SWELL = 0.1

# ---- katman nesne listeleri ----
L = {k: [] for k in ("top_cu","bot_cu","top_mask","bot_mask","top_silk","bot_silk","edge")}
drills_pth, drills_npth = [], []          # (x,y,dia)
NETS = {}                                  # net -> list[(x,y)]
PADLABELS = []                             # (x,y,text) assembly drawing icin
OUTLINES = []                              # (x,y,w,h,label) silk + assembly
ALLPADS = []                               # (x,y,net,cu) tum THT padler (pour clearance icin)
SMDPADS = []                               # (x,y,net)
VIAS = []                                  # (x,y,net)

def net(name, x, y):
    NETS.setdefault(name, []).append((x, y))

# ---- pad / via primitifleri ----
def tht_pad(x, y, net_name=None, cu=PAD_CU, dr=PAD_DR, square=False):
    if square:
        L["top_cu"].append(go.Flash(x, y, ap.RectangleAperture(cu, cu, unit=MM), unit=MM))
        L["bot_cu"].append(go.Flash(x, y, ap.RectangleAperture(cu, cu, unit=MM), unit=MM))
        L["top_mask"].append(go.Flash(x, y, ap.RectangleAperture(cu+MASK_SWELL, cu+MASK_SWELL, unit=MM), unit=MM))
        L["bot_mask"].append(go.Flash(x, y, ap.RectangleAperture(cu+MASK_SWELL, cu+MASK_SWELL, unit=MM), unit=MM))
    else:
        for lay in ("top_cu","bot_cu"):
            L[lay].append(go.Flash(x, y, ap.CircleAperture(cu, unit=MM), unit=MM))
        for lay in ("top_mask","bot_mask"):
            L[lay].append(go.Flash(x, y, ap.CircleAperture(cu+MASK_SWELL, unit=MM), unit=MM))
    drills_pth.append((x, y, dr))
    ALLPADS.append((x, y, net_name, cu))
    if net_name: net(net_name, x, y)

def smd_pad(x, y, w, h, net_name=None):
    L["top_cu"].append(go.Flash(x, y, ap.RectangleAperture(w, h, unit=MM), unit=MM))
    L["top_mask"].append(go.Flash(x, y, ap.RectangleAperture(w+MASK_SWELL, h+MASK_SWELL, unit=MM), unit=MM))
    SMDPADS.append((x, y, net_name))
    if net_name: net(net_name, x, y)

def via(x, y, net_name=None):
    for lay in ("top_cu","bot_cu"):
        L[lay].append(go.Flash(x, y, ap.CircleAperture(VIA_CU, unit=MM), unit=MM))
    drills_pth.append((x, y, VIA_DR))
    VIAS.append((x, y, net_name))
    if net_name: net(net_name, x, y)

# ---- silk yardimcilari ----
def silk_rect(x, y, w, h, side="top"):
    lay = "top_silk" if side=="top" else "bot_silk"
    a = ap.CircleAperture(0.15, unit=MM)
    pts = [(x-w/2,y-h/2),(x+w/2,y-h/2),(x+w/2,y+h/2),(x-w/2,y+h/2),(x-w/2,y-h/2)]
    for (x1,y1),(x2,y2) in zip(pts, pts[1:]):
        L[lay].append(go.Line(x1,y1,x2,y2,a,unit=MM))

def silk_dot(x, y):
    L["top_silk"].append(go.Flash(x, y, ap.CircleAperture(0.5, unit=MM), unit=MM))

# ---- footprint: pin header / modul ----
def header(refx, refy, ncols, nrows, pitch, rowsp, nets_map, label,
           pin1=(0,0), term=False, body=None):
    """nets_map: {(col,row): netname}. Pad indeksleri sol-alttan."""
    cu, dr = (TERM_CU, TERM_DR) if term else (PAD_CU, PAD_DR)
    for c in range(ncols):
        for r in range(nrows):
            x = refx + c*(rowsp if ncols>1 else 0) if False else refx + c*pitch_or_row(c, ncols, pitch, rowsp)
    # basit: iki boyutlu izgara, x = col ekseni, y = row ekseni
    pads=[]
    for r in range(nrows):
        for c in range(ncols):
            x = refx + c*(rowsp if rowsp and ncols>1 else pitch)
            y = refy + r*pitch
            nm = nets_map.get((c,r))
            tht_pad(x, y, nm, cu=cu, dr=dr, square=(c==0 and r==0))
            pads.append((c,r,x,y,nm))
    # govde + pin1
    if body:
        bw,bh = body
        cx = refx + (rowsp if (rowsp and ncols>1) else pitch*(ncols-1))/2
        cy = refy + pitch*(nrows-1)/2
        silk_rect(cx, cy, bw, bh)
        OUTLINES.append((cx, cy, bw, bh, label))
        PADLABELS.append((cx, cy, label))
    silk_dot(refx-1.4, refy-1.4)
    return pads

def pitch_or_row(c, ncols, pitch, rowsp):
    return (rowsp if (rowsp and ncols>1) else pitch)

# ============================================================================
#  YERLESIM  (mm) -- bilesenler cevreye, ESP32 ortada
# ============================================================================
# --- U1: ESP32-DevKitC 30 pin (2x15), satir araligi 25.4mm ---
ESP_X, ESP_Y, P = 36.0, 16.0, 2.54
esp_nets = {
    # sol kolon (c=0)            sag kolon (c=1)
    (0,0):"N_3V3",  (1,0):"N_GND",
    (0,1):"N_EN_BTN",(1,1):"GPIO23",
    (0,5):"N_THDIR",(1,5):"N_THSTEP",   # gpio18 / gpio19
    (0,6):"N_RHDIR",(1,6):"N_RHSTEP",   # gpio5  / gpio21
    (0,7):"N_UART", (1,7):"N_UART_RX",  # gpio17 / gpio16
    (0,8):"N_EN",   (1,8):"N_ENDSTOP",  # gpio25 / gpio22
    (0,9):"N_LEDG", (1,4):"N_5V",       # gpio4  ; 5V pin
    (1,14):"N_GND",
}
header(ESP_X, ESP_Y, 2, 15, P, 25.4, esp_nets, "U1 ESP32",
       body=(28.0, 15*P+2))

# --- A1 (theta) ve A2 (rho) TMC2209 StepStick: 2x8, satir araligi 12.7mm ---
def stepstick(refx, refy, label, prefix, motor_conn):
    # sol kolon: EN,MS1,MS2,UART,STEP,DIR,VIO,GND ; sag: VM,GND,coilB-,coilB+,coilA-,coilA+,(2)
    nm = {
        (0,7):"N_EN", (0,6):"N_MS1", (0,5):"N_MS2", (0,4):"N_UART",
        (0,3):prefix+"STEP", (0,2):prefix+"DIR", (0,1):"N_5V", (0,0):"N_GND",
        (1,7):"N_12V",(1,6):"N_GND",
        (1,5):motor_conn+"_B2",(1,4):motor_conn+"_B1",
        (1,3):motor_conn+"_A2",(1,2):motor_conn+"_A1",
        (1,1):"N_GND",(1,0):"N_GND",
    }
    return header(refx, refy, 2, 8, P, 12.7, nm, label, body=(12.7+4, 8*P+1))

stepstick(8.0,  26.0, "A1 TMC(th)", "N_TH", "THM")
stepstick(78.0, 26.0, "A2 TMC(rh)", "N_RH", "RHM")

# --- BK1 buck 12V->5V : 1x4 (IN+ IN- OUT+ OUT-) ---
header(40.0, 64.0, 4, 1, P, P, {(0,0):"N_12V",(1,0):"N_GND",(2,0):"N_5V",(3,0):"N_GND"},
       "BK1 5V", body=(4*P+1, 5))

# --- J_PWR 12V girisi (2p klemens 5.08) ---
header(6.0, 64.0, 2, 1, 5.08, 5.08, {(0,0):"N_12V",(1,0):"N_GND"}, "J1 12V", term=True,
       body=(2*5.08+2, 7))
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

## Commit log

2026-06-09 Kinetik kum sanati masasi uretim projesi (polar/theta-rho, Ø60cm)
    - README: genel bakis, calisma prensibi, hizli baslangic
    - BOM: malzeme listesi + TR tedarik linkleri + maliyet
    - hardware/sand_table.scad: parametrik 3D model
    - hardware/pcb: KiCad sema spesifikasyonu + pin haritasi
    - firmware: Dune Weaver kurulumu + Sandify desen uretimi
    - docs/render-recipe: Blender/KeyShot fotogercekci render recetesi
    [sand_table.scad]
2026-06-09 PCB: kontrol karti Gerber + Excellon + 3D + netlist + katman cizimleri
    - pcb_gen.py: gerbonara ile kod-tabanli kart uretici (KiCad gerektirmez)
    - 100x75mm 2 katman: ust sinyal/guc, alt GND ground plane (clearance'li)
    - Tam Gerber seti (.gtl/.gbl/.gts/.gbs/.gto/.gbo/.gko) + PTH/NPTH Excellon
    - 26/32 segment otomatik yonlendirme (cakisma kontrollu), 6 ratsnest KiCad'e
    - board3d.scad: kartin 3D dizgi modeli
    - controller.net: KiCad'e aktarilabilir netlist
    - plots/: her katman SVG + assembly drawing (+PNG onizleme)
    - Tum Gerber'lar gerbonara ile round-trip dogrulandi
    [board3d.scad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]
2026-06-09 KiCad final: gercek .kicad_pcb + KiCad-export Gerber + STEP 3D + DRC
    - KiCad 9.0.9 kuruldu (~/Applications), pcbnew API + kicad-cli kullanildi
    - build_kicad.py: standart kutuphane footprintleriyle controller.kicad_pcb
    (ESP32/TMC/buck soketleri, klemensler, 0805/radyal pasifler), net atamasi,
    ped-farkinda iz yonlendirme (0 bakir short), alt katman GND ground plane
    - ZONE_FILLER headless segfault -> SHAPE_POLY_SET ile self-fill (clearance'li)
    - kicad_export.sh: kicad-cli ile final/ Gerber + Excellon + STEP + PDF + DRC
    - final/controller.step (2.1MB ISO-10303 3D), final Gerber seti, DRC raporu
    - DRC: shorting_items=0; kalan clearance/silk kozmetik (KiCad GUI 'B' refill ile temizlenir)
    - REA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
    [controller-B_Adhesive.gbr, controller-B_Courtyard.gbr, controller-B_Cu.gbr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]
2026-06-10 Freerouting: kalan sinyaller tamamlandi -> TAM ROUTING (ratsnest=0)
    - Java 25 (Temurin) + Freerouting 2.2.4 ile headless autoroute
    - pcbnew DSN export headless'ta calismiyor -> make_dsn.py geometriden DSN uretir
    (GND = B.Cu plane), build_kicad.py SES_FILE modu SES'i parse edip uygular
    - freeroute.sh: make_dsn -> Freerouting -> SES uygula -> kicad_export zinciri
    - 23 sinyal neti tam routlu (139 iz + 3 via); GND plane yeni geometriye gore
    yeniden self-fill'lendi
    - DRC: ratsnest=0, short=0, bakir clearance=0 (zone clearance kurali duzeltildi);
    kalan 148 ihlal kozmetik (129 kutuphane silk + ~12 plane artefakti)
    - final/ Gerber + STEP + PDF + DRC yenilendi; F_Cu/B_Cu render'lari eklendi
    - a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
    [controller-B_Adhesive.gbr, controller-B_Courtyard.gbr, controller-B_Cu.gbr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]
2026-06-10 Render: Blender fotogercekci masa render'i (hero + dark)
    - Blender 4.5.10 LTS kuruldu (~/Applications), Cycles + Metal GPU
    - render/render_table.py: prosedurel sahne (sand_table.scad olculeriyle)
    ahsap govde + boolean kum havuzu, cam, taranmis konsantrik kum deseni,
    celik bilye, LED halka; mat ceviz + cam + kum malzemeleri; stuyo isik
    - table_hero.png: aydinlik urun cekimi (kum deseni gorunur)
    - table_dark.png: koyu stuyo, mavi LED halka parlatisi
    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
2026-06-11 Reklam kalitesi: stüdyo render'lar + reklam videosu + interaktif simülasyon + web sitesi
    - render/scene.py: ayakli sehpa + gercek .thr deseni + studyo/oda HDRI + PBR
    ahsap doku haritalari + gelismis kum + parlak zemin + kompozitor post (bloom/vignette)
    - 4 stil (hero/top/room/dark) 2K/384spp; reklam videosu (video modu, 720p, MP4)
    - render/viewer.html: interaktif 3D SIMULASYON - tikla LED yanar + bilye .thr
    desenini gercek zamanli cizer; LED modlari, desen secimi, patlatma;
    HDRI yansima + UnrealBloom + yansitici zemin + golge
    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
2026-06-11 Gerçek oluk (displacement) + sim fix'leri + IKEA patlatma + yol haritası
    - GERCEK OLUK: groove_height.py (.thr -> heightmap), scene.py'de kum artik
    yuksek-coz grid + Displace modifier -> bilye kumu gercekten oyuyor (golgeli
    cukur + kenar kabarma). 4 stil + reklam videosu yeniden render edildi.
    - Sim fix'leri (viewer.html):
    * Atatürk imzasi AYNALI cikiyordu -> glb Y-up donusumu icin sin negatif (render'la eslesir)
    * 'hareket ettiremiyorum' -> otomatik donus kapatildi, tam manuel orbit
    * cam imzayi occlude ediyordu -> depthWrite=false + opak cizgi (ustten gorunur)
    - LED yumusatildi (goze batmayan los glow) sim+render
    - Profesyonel IKEA-tarzi PATLATILMIS montaj cizimi (montaj_3d.py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
2026-06-11 Üretim gerçekleme dosyası: dürüst durum + PCB inceleme + firmware mimarisi
    - docs/uretim/URETIM_DOSYASI.md: profesyonel NPI dosyasi - durust olgunluk durumu
    (PCB FIZIKSEL TEST EDILMEDI), sistem mimarisi, entegrasyon haritasi, uretim akisi,
    EVT/DVT/PVT asamalari, test plani (bring-up), COGS + hedef MSRP (~21.9k TL/~$650)
    + marj analizi, risk kaydi
    - docs/uretim/PCB_inceleme.md: durust elektriksel inceleme - DRC temiz ama uretilmedi;
    bulgular (TMC UART adres cakismasi, WS2812 level-shift, VM bulk cap, giris korumasi,
    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
    [fluidnc_config.yaml]
2026-06-11 PCB Rev-B: inceleme bulgulari islendi + yeniden route (bastirilabilir)
    build_kicad.py Rev-B eklemeleri:
    - TMC2209 UART adres cakismasi -> A1=adr0 (MS1/MS2=GND), A2=adr1 (MS1=5V); ayri adres
    - WS2812 level shifter U2 (74AHCT1G125 SOT-23-5): GPIO4 3.3V -> 5V DIN; R1 cikis serisi
    - 12V giris korumasi: F1 sigorta + Q1 P-FET ters polarite + D1 zener + R2 gate
    - TMC VM: C6 100uF bulk + C7/C8 100nF decap
    - EN boot pasif: R3 10k pull-up (EN->VIO)
    - UART half-duplex: R4 1k (TX->PDN), RX PDN'e taps
    -> Freerouting tam route: 196 iz + 12 via, DRC 0 short / 0 ratsnest / 0 bakir clearance
    yeni Gerber + STEP + DRC uretildi (final/)
    DURUM: Rev-B tasarimi dondurdu; HALA fiziksel uretilmedi/test edilmedi.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
    [controller-B_Adhesive.gbr, controller-B_Courtyard.gbr, controller-B_Cu.gbr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]
2026-06-11 JLCPCB uretim paketi: Gerber zip + BOM.csv + CPL (dizgiye hazir)
    - make_jlcpcb.py: kicad-cli pos -> JLCPCB formatinda CPL (pick&place) + BOM (LCSC) + gerber zip
    - hardware/pcb/jlcpcb/: gerbers_revB.zip, BOM_jlcpcb.csv (9 satir), CPL_jlcpcb.csv (13 SMD), README
    - SMD dizgi: R/C/Q1 yaygin LCSC; U2/D1/F1 'DOGRULA' (JLCPCB kutuphanesinden sec)
    - Elle: ESP32/TMC/buck soketleri, klemensler, elektrolitikler (README'de)
    - Durust: Rev-B test edilmedi; rotasyon/LCSC yuklemede dogrulanmali; 5 adet onerilir
    - muhendislik sayfasina JLCPCB paket linki
    [BOM_jlcpcb.csv, pos_raw.csv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]
2026-06-12 CNC/lazer DXF kesim dosyalari: aluminyum sasi + ayak plakasi + kol
    - docs/uretim/dxf/make_dxf.py (ezdxf): montaj olculeriyle parametrik DXF + onizleme
    - sasi.dxf (Ø520, drum/turntable/NEMA17/PCB delikleri + kablo yuvasi)
    - ayak_plakasi.dxf (60x60, 4x M5 + tenon) x4
    - kol.dxf (320x40, pivot + MGN12 ray + rho motor pateni)
    - README: malzeme/kalinlik + delik semasi + URETIM ONCESI dogrulama uyarisi
    (MGN12 pitch, lazy-susan PCD, slip ring bore gercek parcayla dogrula)
    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
    [ayak_plakasi.dxf, kol.dxf, sasi.dxf]
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2026-06-12 3D STEP modelleri (sasi/ayak/kol) - mekanik CAD dogrulama icin
    - make_step.py (cadquery): DXF profillerinden 3D kati + STEP export
    - sasi.step (Ø520x4, 820cm3), ayak_plakasi.step (60x60x4), kol.step (320x40x5)
    - Fusion/FreeCAD/SolidWorks'te acilip montaj/fitment dogrulamasi icin baslangic CAD
    - dxf/README'ye STEP bolumu (tam fitment icin COTS parca ekle notu)
    [ayak_plakasi.step, kol.step, sasi.step]
2026-06-12 Mekanizma tasarimi: theta/rho kinematik + kesit + hesaplar
    - docs/uretim/mekanizma_tasarim.md: donen-kol polar mimari (PCB J3/J5 + FluidNC ile tutarli)
    * theta: lazy-susan yatak + GT2 3:1 reduksiyon -> 26.667 step/derece (~0.16mm @R250)
    * rho: MGN12 ray + GT2 -> 80 step/mm (0.0125mm), strok ~250mm, endstop home
    * slip ring: rho motor 4 + endstop 2 = 6 hat (sureculer bazda, PCB ile tutarli)
    * miknatis/aralik, yukseklik-sigma butcesi, mekanizma BOM, riskler+dogrulama
    - mekanizma_kesit.py -> kesit diyagrami (katmanlar, theta/rho, aralik, cozunurluk)
    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
    [fluidnc_config.yaml]
2026-06-12 Profesyonel elektrik montaj + QA/FCT dokumantasyonu (ayri elektrik/materyal)
    - wiring_diagram.py -> wiring_diagram.png: baglanti/harness semasi
    (kart, SMPS, theta/rho motor, slip ring, LED; tel renk+AWG+pinout+lejant)
    - elektrik_montaj.md: ELEKTRIK is talimati (konnektor pinout J1-J5, slip ring tel
    haritasi, montaj sirasi, guvenlik/CE) -- materyal montaji ayri (montaj.md)
    - QA_kontrol_listesi.md: bring-up/FCT test fisi (olcum degerleri + PASS/FAIL, 8 bolum)
    - elektrik_pdf.py -> ELEKTRIK_TALIMATI.pdf (5 sayfa): kapak + harness semasi +
    pinout/slip ring tablo + 6 montaj adimi + QA test fisi (yazdirlabilir)
    - muhendislik sayfasina elektrik talimati + QA linkleri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
2026-06-12 Modern site (per-doc sayfalar) + reklam videosu duzeltildi
    - style.css bastan: modern premium dark tema (amber vurgu, cam nav, kartlar, prose)
    - build_site.py: her uretim MD'sini modern standalone HTML sayfasina cevirir
    -> 10 ayri sayfa (uretim-dosyasi, pcb-inceleme, mekanizma, elektrik, qa, montaj,
    bom, dxf, firmware, realizm) icerik+gorsel sayfa icinde
    - index/gorseller/simulasyon/muhendislik modern yeniden yazildi; muhendislik = hub
    - VIDEO FIX: imza gorunmuyordu -> video modunda displacement kapali, Groove tube
    gorunur+ilerleyen (acik isikli oluk), daha tepeden kamera -> imza net ciziliyor
    (scene.py: GROOVE3D bayragi, video icin ayri groove materyali, ONEFRAME dogrulama)
    Co-A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
2026-06-12 Profesyonel datasheet + is/yatirim pitch (markali PDF) + siteye baglandi
    - docs/marka_pdf.py -> DEVRAN_datasheet.pdf (1 sayfa urun spec sheet: hero + ozellik + 14 spec)
    + DEVRAN_pitch.pdf (problem/cozum/pazar/is modeli/yol haritasi/talep)
    - markali acik tema, DEVRAN logo bar; index + muhendislik'e indirme linkleri
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2026-06-12 Prototip satin-alma / tedarikci listesi (siparis edilebilir)
    - satin_alma.py -> satin_alma.csv (25 kalem, kategori/adet/tedarikci/birim/toplam/termin)
    - satin_alma.md: siparis stratejisi (uzun-terminliler once) + kategori tablolari +
    tedarikci rehberi (TR) + butce (~11.4k TL malzeme, ~13-14k toplam)
    - site sayfasi (satin-alma.html, CSV indirme) + muhendislik hub karti
    [satin_alma.csv]
